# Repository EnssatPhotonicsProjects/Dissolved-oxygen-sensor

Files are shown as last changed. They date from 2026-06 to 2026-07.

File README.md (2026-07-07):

<p align="center">
  ENSSAT Logo
</p>

# Dissolved-oxygen-sensor

## Description

This project aims to develop a low-cost optode for measuring dissolved oxygen concentration in water, a key indicator of the health of marine environments. The project is conducted by students in photonics from Enssat in collaboration with the European Institute for Marine Studies (IUEM) and is part of an open-source initiative to facilitate easy and cost-effective replication of the device.

This GitHub repository contains all the necessary resources and instructions for understanding and making the device.

The document [Oximeter overview](Oximeter_overview.pdf) aims to provide an overview of the technical aspects of our sensor.

## Features

- Measures the percentage of dissolved oxygen within a range of 0 to 105 %.
- Low-cost (approximately ??), low-tech, and open-source design.
- Portable

## Principle of dissolved oxygen sensor

<p align="center">
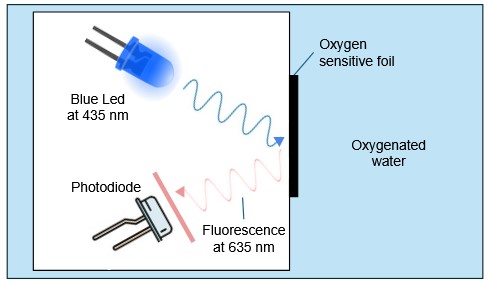
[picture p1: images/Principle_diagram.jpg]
Principle diagram
  
</p>
The measurement principle is based on the use of a luminophore. An emitting blue light is absorbed by a sensitive foil exposed to water. Then it returns red light through fluorescence. By measuring the phase shift between the blue and red signal, the concentration of dissolved oxygen can be determined.

## Functionality

<p align="center">
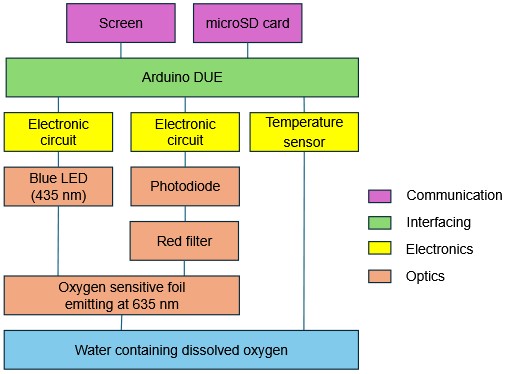
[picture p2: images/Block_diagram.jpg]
Block diagram
  
</p>

The Arduino DUE coordinates the entire system. To ensure speed and accuracy, the microcontroller uses synchronous detection. It drives a blue LED (435 nm) for excitation and detects the resulting fluorescence at 635 nm using a photodiode (isolated by a red filter). A temperature sensor is installed for measurements. Finally, the data is displayed on the OLED screen and saved to the MicroSD card.

## Components

The main components are:

| Component | Description |
|---|---|
| LED | Light Emitting Diode for blue excitation |
| Oxygen sensitive foil | Emits red fluorescence linked to the oxygen concentration |
| Photodiode | Detects red fluorescence |
| Arduino | Microcontroller for processing |
| Temperature Sensor | Measures the temperature |
| OLED Screen | Displays values |
| MicroSD Card Shield | Saves data to a MicroSD card |

For a detailed list of components with the references, please refer to the [Components List](hardware/components.md).

## Construction of the device : OXIMETER

### Prerequisites

- Arduino IDE
- Electronic components
- Soldering equipment
- 3D printer
- Laser cutter

### Installation Steps

1. **Clone the Repository:**

   ```bash
   git clone https://github.com/EnssatPhotonicsProjects/Dissolved-oxygen-sensor.git
   ```

### Assembling the dissolved oxygen sensor

Follow the steps of the [assembly guide](assembly_guide.md) to build the dissolved oxygen sensor.

## Avenues for Improvement

- ...

Contributions are welcomed to improve these points.

## To contribute

Contributions to this project are welcomed. To contribute, follow these steps:

1. **Fork the repository** and create your branch:

   ```bash
   git checkout -b my-new-feature
   ```

2. **Make your changes** and test them thoroughly.

3. **Document your changes** in the [EXTERNAL_CONTRIBUTIONS](EXTERNAL_CONTRIBUTIONS.md) file. Begin the file with your name, location and date.

4. **Submit a Pull Request** with a detailed description of your changes.

## Contributors

Team 2025-2026 :
- Arthur Allaeys (IntricationQuantique)
- Elisa Charron (Quazou54)
- Brice Chupin (bricechup)
- Léon Dolaine
- Constant Ekpo
- Ethan Geffroy
- Nathan Maës
- Alexandre Martin-Lefèvre
- Adam Monzon
- Lucile Pointud
- Sean Swidurski

## Acknowledgments

The authors warmly thank Laurent Bramerie, Thierry Chartier, Antoine Courtay supervisors of the project at Enssat, Philippe Laborie (Laboratoire de physique corpusculaire, Caen, France) and Etienne Poirier (IUEM, Plouzané, France), members of the steering committee, for their advice and support throughout the project. 

Special thanks to Etienne Poirier for giving the idea of the project, helping us, trusting us and welcome us at IUEM in the last days of the project.

Authors are also very grateful to Pierre Guilleme teacher at Enssat, and Jean-Philippe Lesault, technician at Enssat, for their advice and technical support. Specific thanks to Yvan Guilloit, in charge of the MakerSpace at IUT de Lannion, France, for his help in the integration of the device in the waterproof box.

The dissolved oxygen sensor project started in september 2025 with a first team of Enssat students.

## License

This project is licensed under [CC BY-SA 4.0]. Please see the [LICENSE](LICENSE.md) file for more details.

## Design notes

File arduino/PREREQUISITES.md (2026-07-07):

# Prerequisites & code configuration

This document outlines the arduino dependencies and code architecture required to compile and run the open-source dissolved oxygen sensor (Oximeter) firmware.

> **WARNING :** This firmware is designed strictly for the Arduino Due (3.3V ARM Cortex-M3 SAM3X8E architecture). It relies on low-level hardware registers (Hardware Timers `TC0`, analog-to-digital conversion `ADC` and digital-to-analog conversion `DAC`).

## Arduino dependencies

Before compiling in the Arduino IDE, ensure the following external libraries are installed via the Library Manager : <br>
(`Sketch` > `Include Library` > `Manage Libraries...`)

### External libraries to install:
* **`U8g2`** : Monochrome display library for the OLED display.
* **`OneWire`** : Digital communication protocol for the OneWire temperature probe.
* **`DallasTemperature`** : Data extraction for the OneWire temperature probe.

### Native libraries (Included with Arduino SAM Boards package):
* **`SPI`** : High-speed communication for the MicroSD card shield.
* **`SD`** : FAT16/FAT32 file system management for data logging.
* **`Wire`** : I2C communication for the OLED display (utilizing the Due's secondary I2C port `Wire1`).

## Code architecture

The firmware follows the single responsibility principle, dividing the system into isolated modules. All of these modules must be placed in a folder named [Oximeter](arduino/Oximeter/):

```text
Oximeter/
├── Oximeter.ino              # System orchestrator (main loop and measurement cycle sequencing)
├── synchronous_detection.*   # Low-level lock-in amplifier (Timer ISRs, DAC sine modulation, ADC reads)
├── tools.*                   # Mathematical models (F0 noise subtraction, Stern-Volmer, polynomial fit)
├── complex.*                 # Custom operator for complex number arithmetic (+, -, *, /)
├── temperature.*             # Temperature reads with safe interrupt management (Non-blocking)
├── display.*                 # OLED visual interfaces (boot status, live results, progress bar)
└── microSD_card.*            # Data logging (automatic session file creation and TSV data writing)

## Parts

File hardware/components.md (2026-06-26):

# List of components

## Optical components

| Component | Manufacturer - Ref | Seller - Ref | Quantity | Price per unit |
|---|---|---|---|---|
|Oxygen sensitive spot|Presens - PSt3-SA series|[Presens - PSt3-SA23-D5-YOP-US](https://www.presens.de/oemcustom/detail/self-adhesive-oxygen-sensor-spot-sp-pst3-sa)|1|33.75 €|
|LED|Thorlabs - LED430L|[Thorlabs - LED430L](https://www.thorlabs.com/item/LED430L)|1|13.29 €|
|Photodiode|Thorlabs - FDS100|[Thorlabs - FDS100](https://www.thorlabs.com/item/FDS100)|1|15.95 €|
|Red filter|Lee Filters - 182 Light Red|[Lee Filters - 182 Light Red](https://www.la-bs.com/ArticleDetails.aspx?Code=FL182)|1|12.16 €|

## Electronic components

| Component | Manufacturer - Ref | Seller - Ref | Quantity | Price per unit |
|---|---|---|---|---|
|Carte Arduino DUE|Arduino - A000062|[RS - 769-7412](https://fr.rs-online.com/web/p/arduino/7697412)|1|53.35 €|
|OLED Screen 128x64|Midas - MDOB128064V2V-YI|[RS - 225-6203](https://fr.rs-online.com/web/p/afficheurs-oled/2256203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)|1|14.98 €|
|MicroSD Card Shield|Whadda - WPI304N|[GO TRONIC - 38094](https://www.gotronic.fr/art-modules-pour-microsd-wpi304n-36272.htm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)|1|9.90 €|
|Temperature sensor|TRU COMPONENTS TC-9445340|[Conrad - 2361335-62](https://www.conrad.fr/fr/p/tru-components-tc-9445340-capteur-de-temperature-1-pc-s-convient-pour-kits-de-developpement-arduino-2361335.html)|1|6.99 €|
|Powerbank|Output 5 V - 2.4 A, dim. 100x50x25 mm max|[VRURC 2000mAh mini power bank](https://www.amazon.fr/gp/product/B099F29H7Y?smid=A2BNE5LRDUXQ6R&th=1)|1|30 €|
|Voltage converter|Analog Devices - MAX660CPA+|[Mouser - 700-MAX660CPA](https://www.mouser.fr/ProductDetail/700-MAX660CPA)|1|9.37 €|
|Transistor|Micro Commercial Components - PN2222A-AP|[Mouser - 833-PN2222A-AP](https://www.mouser.fr/ProductDetail/Micro-Commercial-Components-MCC/PN2222A-AP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)|1|< 1 €|
|Operational amplifier|Texas Instruments - TL081CP|[Mouser - 595-TL081CP](https://www.mouser.fr/ProductDetail/595-TL081CP)|2|0.60 €|
|Resistor 50 Ω|||1|< 1 €|
|Resistor 66 Ω|||1|< 1 €|
|Resistor 1,2 kΩ|||2|< 1 €|
|Resistor 4,6 kΩ|||2|< 1 €|
|Resistor 10 kΩ|||1|< 1 €|
|Resistor 912 kΩ|||1|< 1 €|
|Capacitor 1 nF|||1|< 1 €|
|Capacitor 47 nF|||1|< 1 €|
|Capacitor 150 µF|||2|< 1 €|

## Case and support components

| Component | Reference | Quantity | Price per unit |
|---|---|---|---|
| Filament PLA black | | | |
| PVC sleeve | 100 mm diameter | 1 | 1.50 € |
| PVC plug | 100 mm diameter | 2 | 3.70 € |
| PMMA thickness 2 mm | | | € |
| PMMA thickness 3 mm | | | € |
| Screws, nuts, washers, spacers | - | | € |

## Final price

The price is estimated in **June 2026** at ** without delivery**.

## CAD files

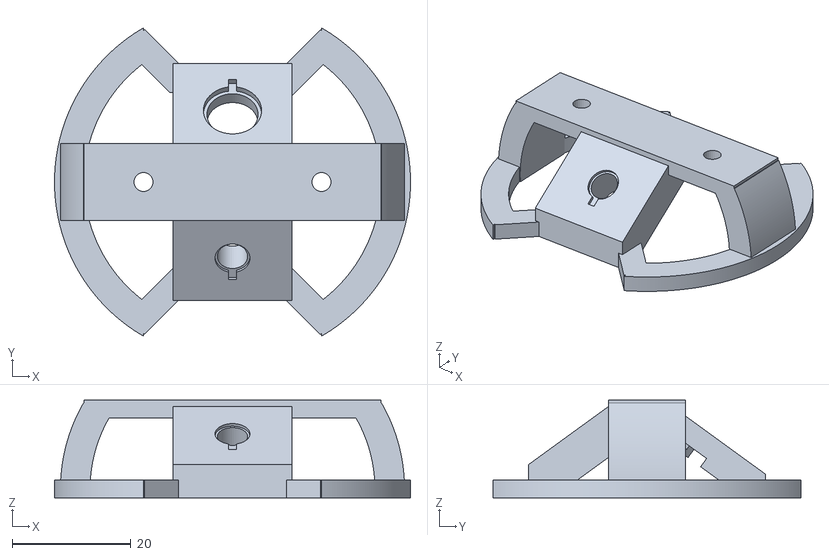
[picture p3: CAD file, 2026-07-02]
hardware/Ready_to_print_LED-photodiode-support.stl
60.0 x 52.0 x 16.5

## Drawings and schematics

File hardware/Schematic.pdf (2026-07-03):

## 3 JP1

## 6 BT

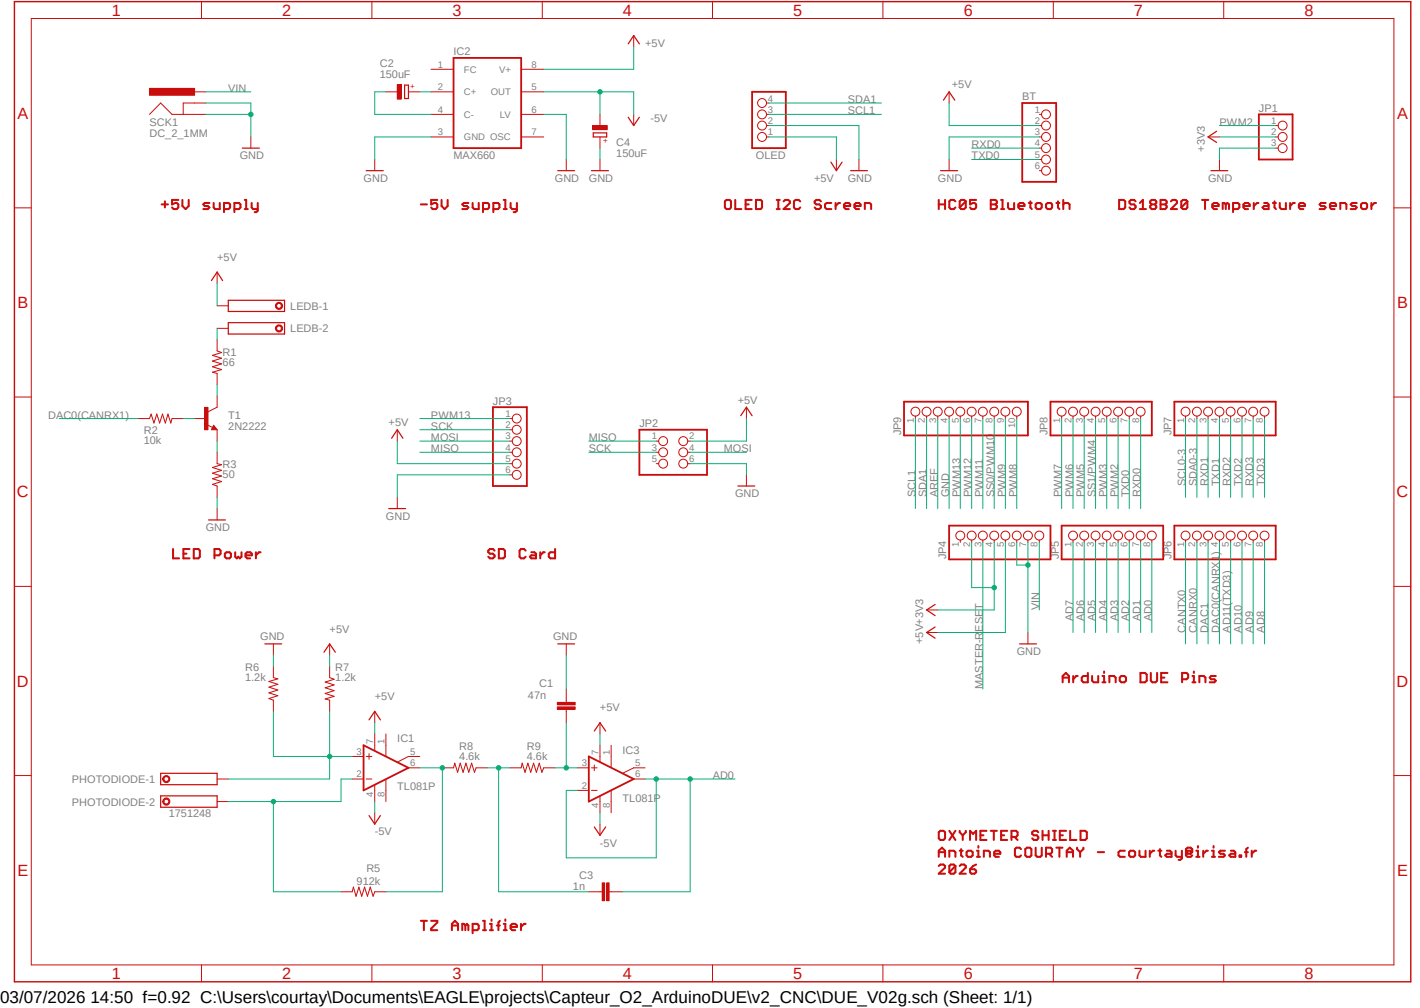
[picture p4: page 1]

03/07/2026 14:50 f=0.92 C:\Users\courtay\Documents\EAGLE\projects\Capteur_O2_ArduinoDUE\v2_CNC\DUE_V02g.sch (Sheet: 1/1)

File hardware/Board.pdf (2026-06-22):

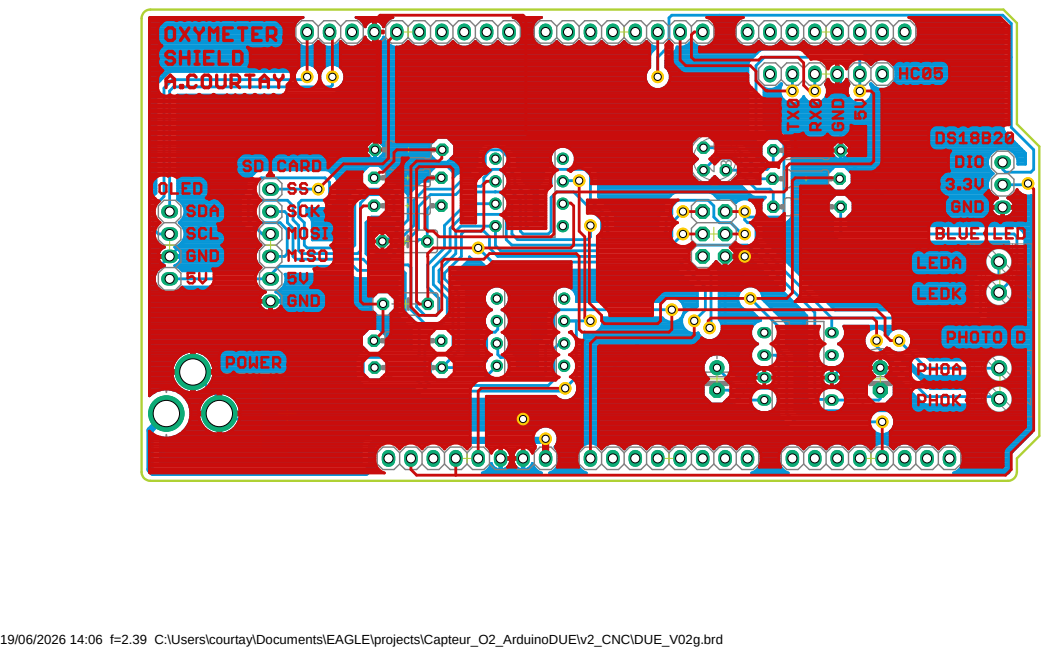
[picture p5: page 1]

19/06/2026 14:06 f=2.39 C:\Users\courtay\Documents\EAGLE\projects\Capteur_O2_ArduinoDUE\v2_CNC\DUE_V02g.brd

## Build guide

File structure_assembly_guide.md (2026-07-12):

# Assembly Guide for Support Structures

This guide provides detailed instructions on how to assemble the Dissolved-oxygen-sensor structures.

## Prerequisites

Before starting the assembly process, ensure you have the following tools and components ready:

- Components from the [Components List](hardware/components.md)
- PVC glue
- Sandpaper
- PVC stripper
- Laser cutter
- Screws, nuts, washers, spacers
- Paper towel or rag
- Wires (red and black)
- Soldering station

## Step 1 : Assemble the LEDs and photodiode support

Start by soldering wires to the LEDs and photodiode terminal. Pay attention to the polarity of the terminals : you can solder a red wire on the + terminals of the LED and the cathode terminal of the photodiode. A black wire can be soldered on the - terminals of the LEDs and on the anode of the photodiode.

When this is done, you can assemble following components :
- Blue LED
- Photodiode
- (Red filter : 19 x 18 mm) X2
- [3D printed support](Ready_to_laser_cut_LED-photodiode-support.stl)

<p align="center">
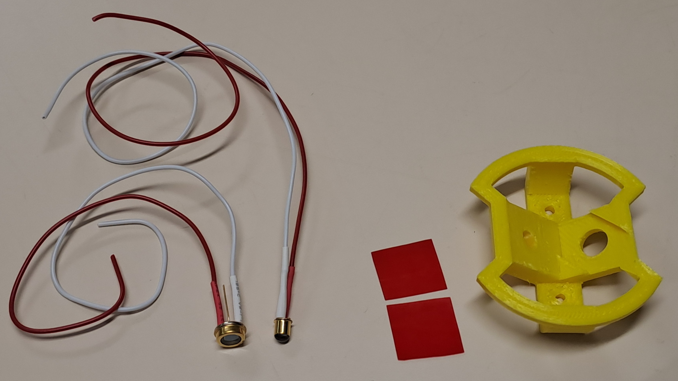
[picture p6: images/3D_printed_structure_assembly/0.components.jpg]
0.components
  
</p>

1. Position the LED and the photodiode in their location. If they do not fit, you can lightly file the inside of the holes. The components must be perfectly held by the support and must not move. The wires must come out of the back of the bracket. You can add small pieces of adhesive tape to the edges of the LED and the photodiode to ensure they do not slip out of the holders.

<p align="center">
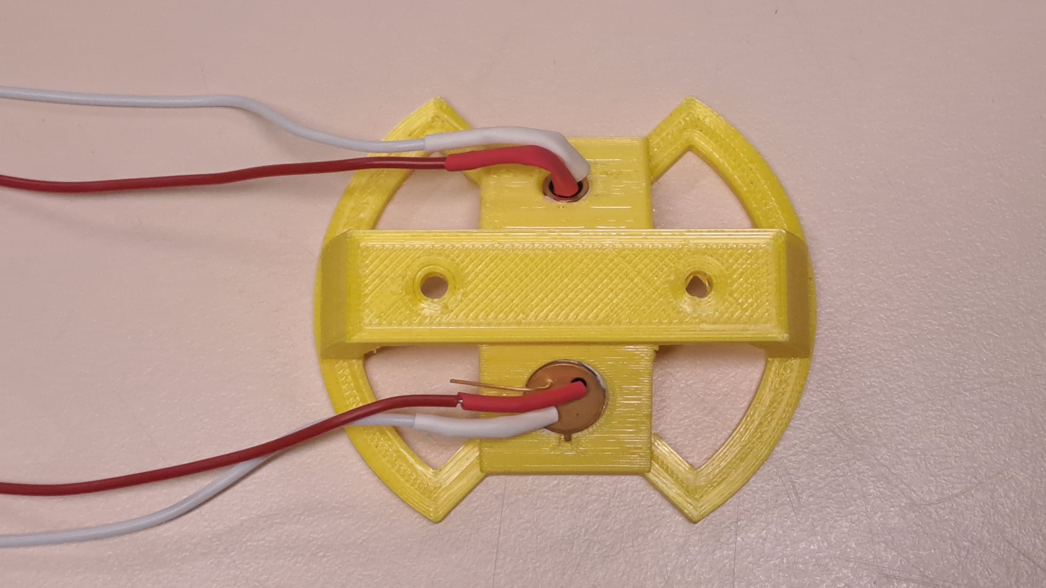
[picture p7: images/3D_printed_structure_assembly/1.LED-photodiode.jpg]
1.LED-photodiode
  
</p>

2. Add the two pieces of red filter. You can slide them in front of the photodiode location.

<p align="center">
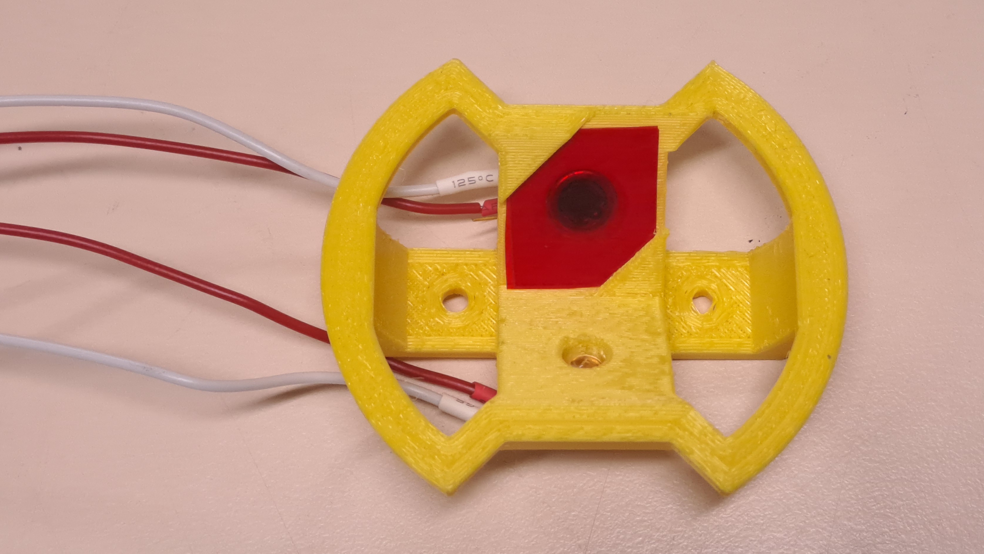
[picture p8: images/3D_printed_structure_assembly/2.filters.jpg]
2.filters
  
</p>

## Step 2 : Assemble the internal structure

The materials required for this step are :
- The Arduino DUE board
- The PCB board with all the electronic components (Screen, SD Card shield, temperature sensor)
- 3 screws, diameter 3 mm, length 5?? mm + 6 nuts
- 16 spacers of 30 mm
- 4 countersunk screw, diameter 3 mm, length 8?? mm + nuts + washers
- 2 screws, diameter 3 mm, length 10?? mm + nuts 
- 4 screws, diameter 2 mm, length ?? mm + 8 nuts + washers
- A powerbank (100 x 50 x 2.5) mm max
- A output power supply and angled USB output cable
- The LED and photodiode AD support made in the previous step
- PMMA sheet or wood, thickness 3 mm
- PMMA sheet, thickness 1.5 mm
- Screwdrivers
- Laser cutter

<p align="center">
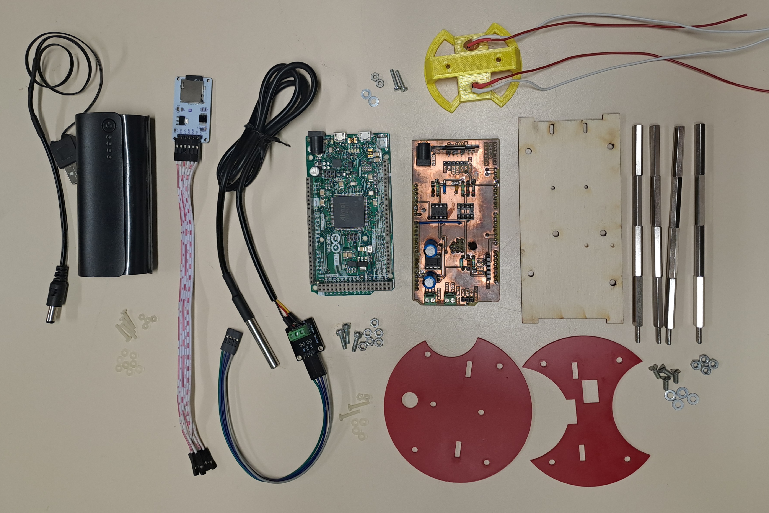
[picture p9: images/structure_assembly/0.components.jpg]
0.components
  
</p>

1. Cut the structure in the PMMA sheets with the laser cutter. In 1.5 mm PMMA, cut the [plates](hardware/Ready_to_laser_cut_plates.svg). In 3 mm PMMA, cut the [mount](hardware/Ready_to_laser_cut_mount.svg).

<p align="center">
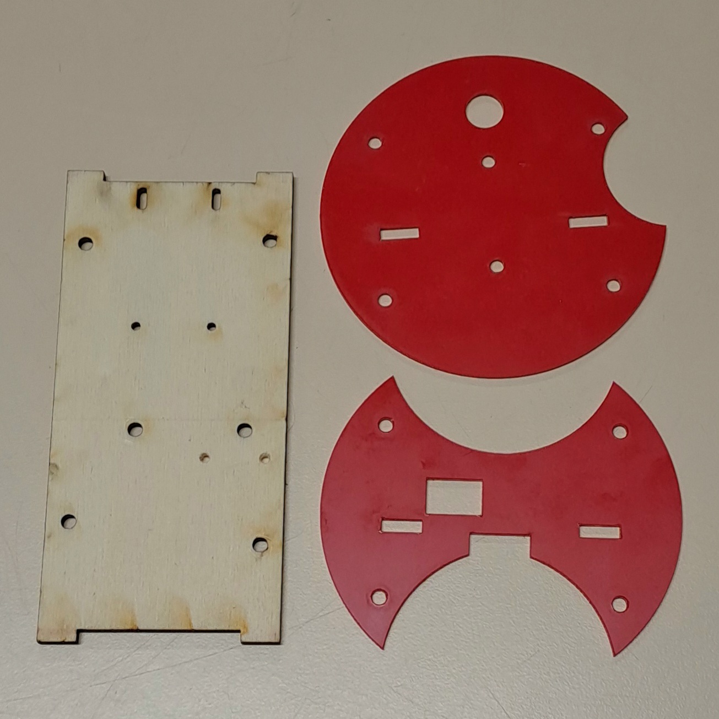
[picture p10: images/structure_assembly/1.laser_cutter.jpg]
1.laser_cutter
  
</p>

2. Screw 3 screws and nuts to the Arduino board, as shown in the photo below. Connect the PCB to the Arduino board.

<p align="center">
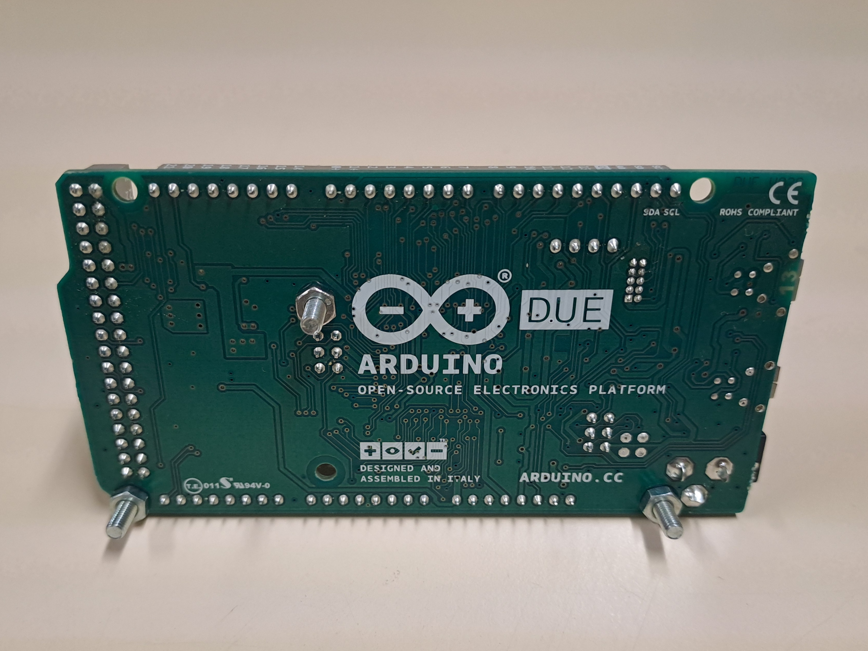
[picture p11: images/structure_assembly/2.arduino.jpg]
2.arduino
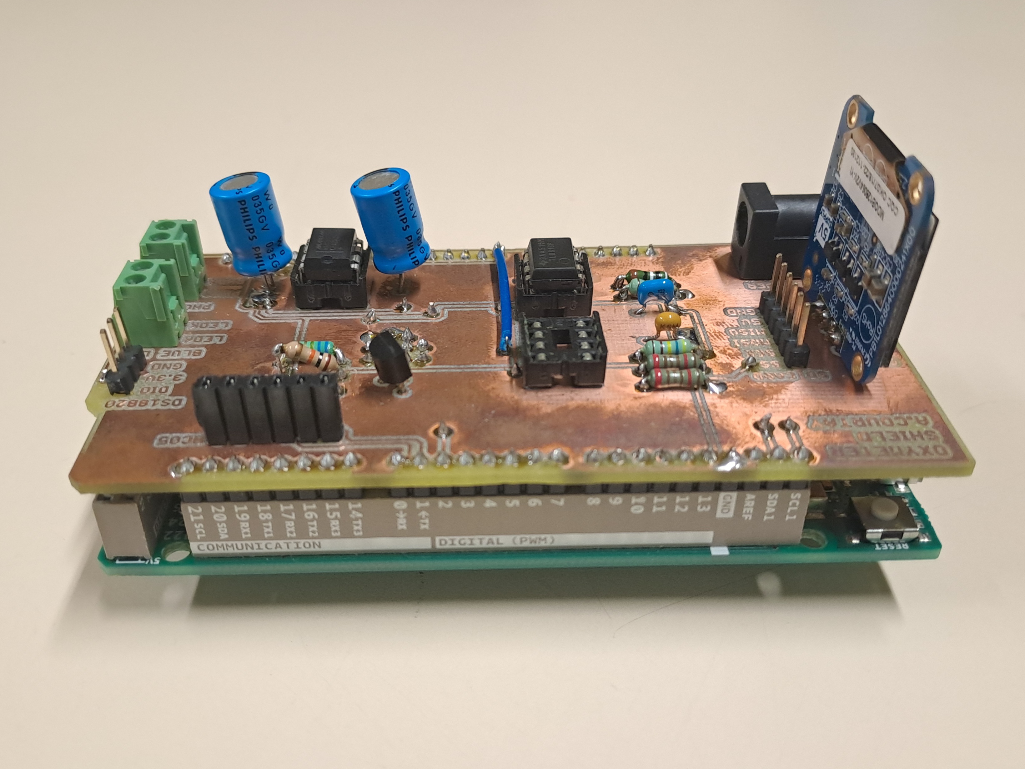
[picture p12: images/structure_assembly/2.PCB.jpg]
2.PCB
   
</p>

3. Take the face plate. Locate the side where the Arduino board goes. On the opposite side, screw the SD Card shield. Put a nuts between the shield and the plate.

<p align="center">
  3.modules
</p>

4. Screw the Arduino board on the opposite face of the plate.

<p align="center">
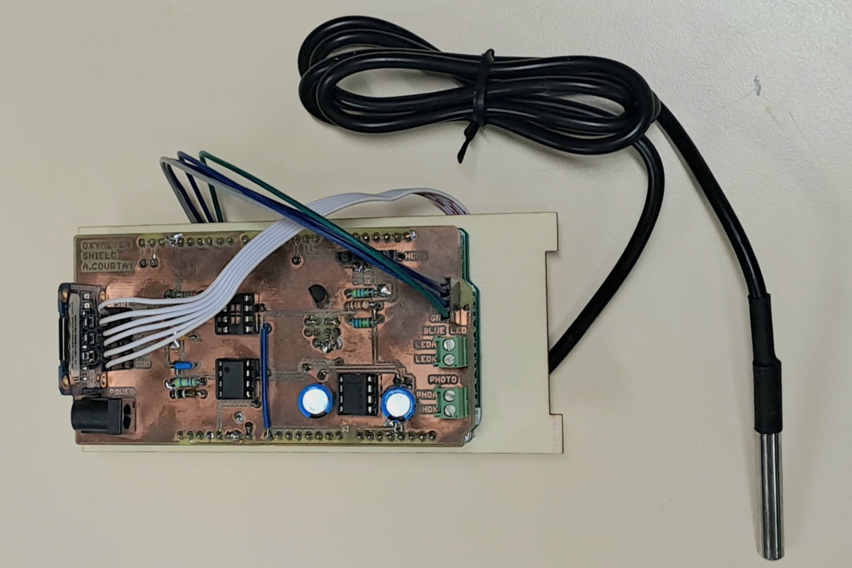
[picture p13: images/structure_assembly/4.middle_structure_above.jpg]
4.middle_structure_above
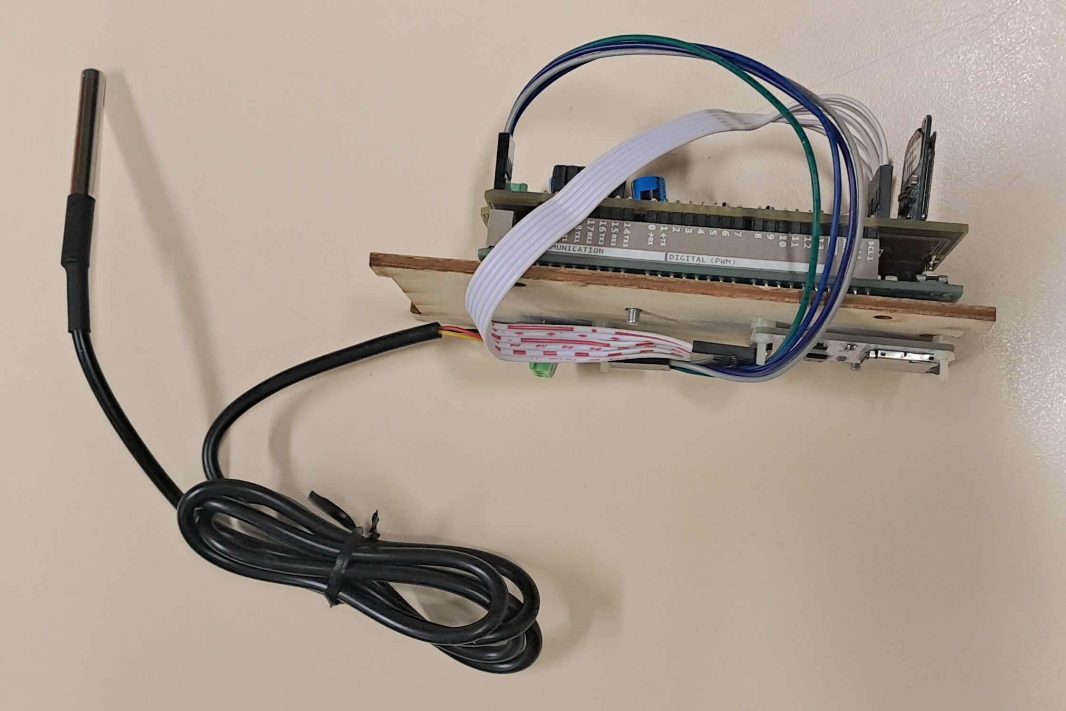
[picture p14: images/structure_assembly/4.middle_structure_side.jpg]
4.middle_structure_side
   
</p>

5. Take the bottom plate and the LED and photodiode support. Screw this support under the bottom plate. Make sure that the large hole in the plate is on the same side as the wires. Pass the wires through the hole.

<p align="center">
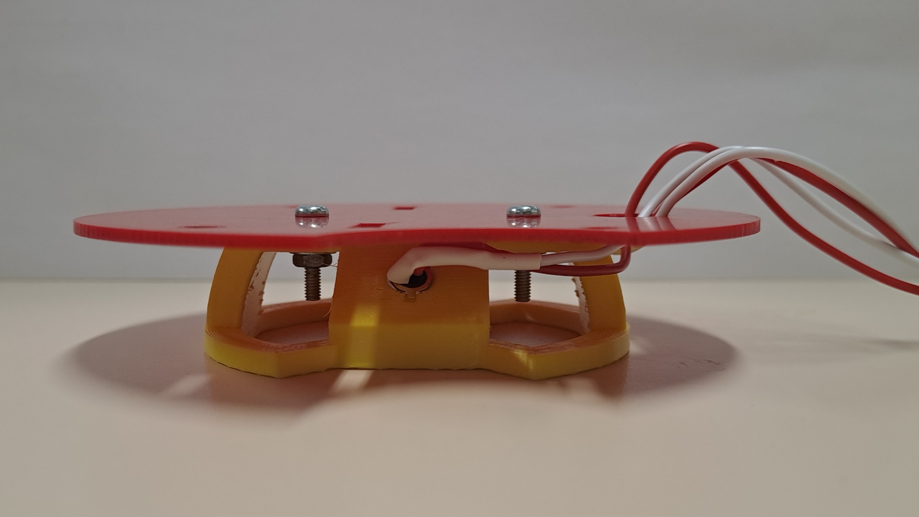
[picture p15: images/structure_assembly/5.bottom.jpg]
5.bottom
  
</p>

6. Screw the LED and photodiode wires into terminal strips of the PCB. Make sure to connect the cathode and anode to the correct terminals.

<p align="center">
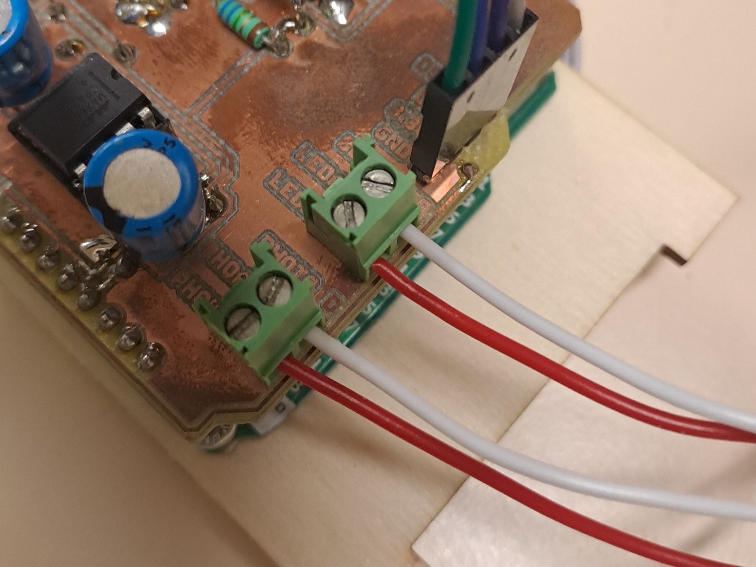
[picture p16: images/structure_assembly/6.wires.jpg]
6.wires
  
</p>

7. Screw the 30 mm spacers into the four corners of the middle plate and put the middle structure, bend the wires of the LED and photodiode, without moving LED and photodiode.

<p align="center">
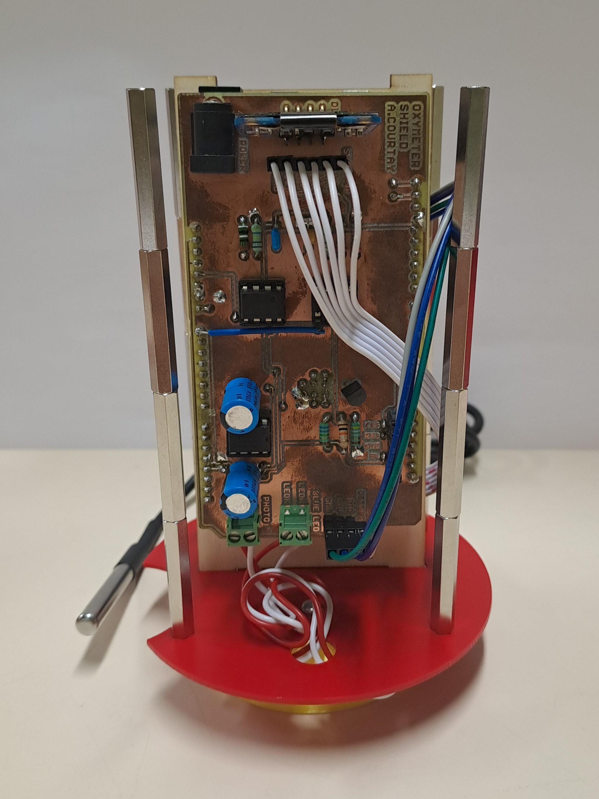
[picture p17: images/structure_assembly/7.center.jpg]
7.center
  
</p>

8. Screw the top plate.

<p align="center">
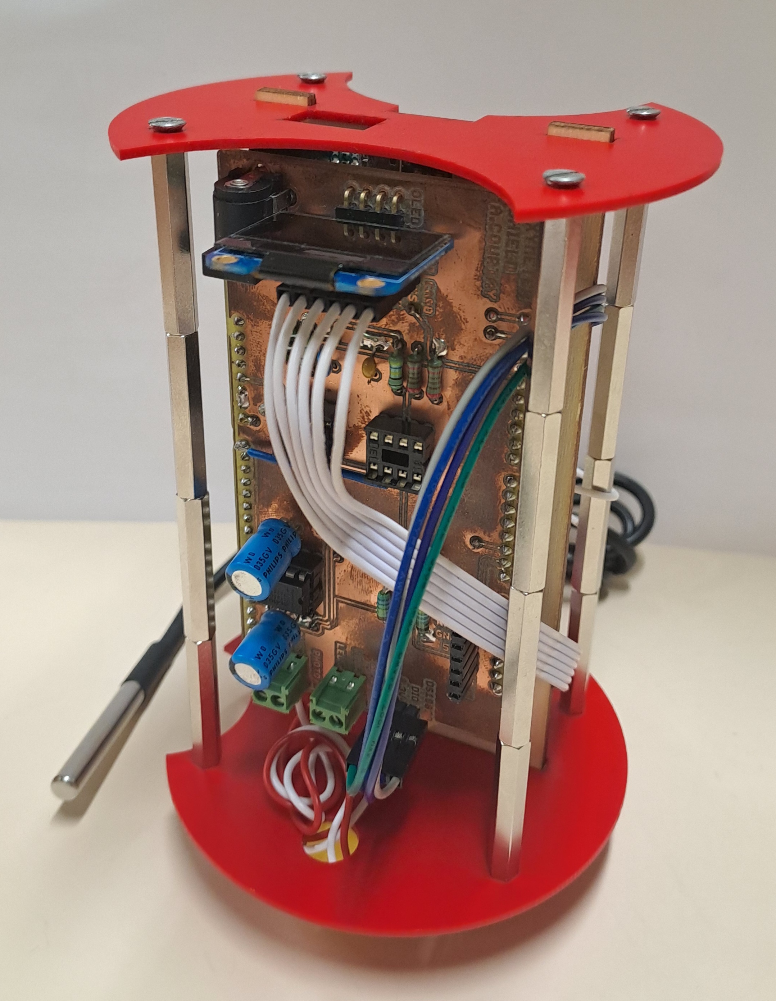
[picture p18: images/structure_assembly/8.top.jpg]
8.top
  
</p>

9. Put the powerbank and the alimentation cable. Fasten it to the spacers with a cable tie.

<p align="center">
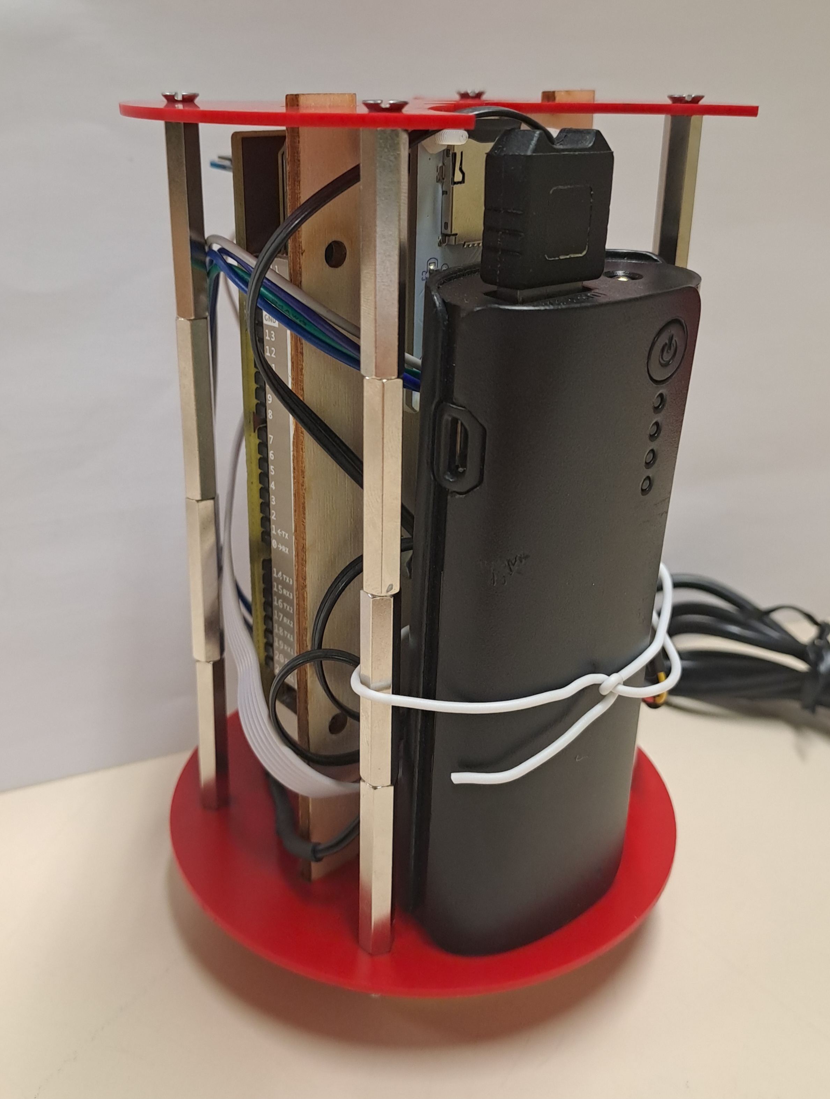
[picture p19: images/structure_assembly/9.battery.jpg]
9.battery
  
</p>

10. Attach the temperature sensor cable to the spacers located between the battery and the opening in the plate. The cable should extend upwards, with a disponible length of approximately 40 cm, to facilitate positioning within the housing.

<p align="center">
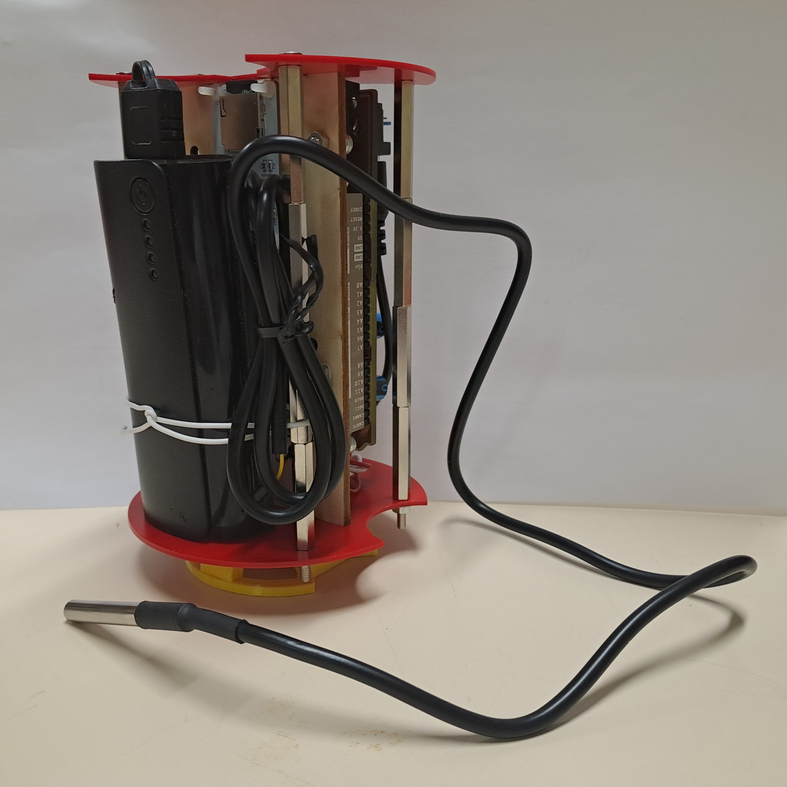
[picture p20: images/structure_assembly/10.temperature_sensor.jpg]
10.temperature_sensor
  
</p>

## Step 3 : Assemble the waterproof box

In this step, you will need :
- PVC sleeve
- Two PVC inspection plugs
- transparent PMMA plate
- cable gland (taille ??)
- PVC glue
- Sandpaper
- PVC stripper
- Laser cutter
- Paper towel or rag

## Step 4 : Assemble the fluorometer

Slide the internal structure into the box. It must be at the bottom and must not move. Switch on the battery, and close the box.

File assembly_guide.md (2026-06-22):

# Assembly Guide for oxymeter

This guide provides detailed instructions on how to assemble the oxymeter device.

## Prerequisites

Before starting the assembly process, ensure you have the following tools and components ready:

- Arduino IDE installed on your computer
- All electronic components listed in the [Components List](hardware/components.md)
- 3D printer for printing support structures
- Laser cutting for support structures
- Soldering equipment for assembling electronic circuits
- Basic hand tools (screwdrivers, pliers, etc.)

## Step 1: Clone the Repository

To get started, clone the project repository to your local machine:

```bash
git clone https://github.com/EnssatPhotonicsProjects/Dissolved-oxygen-sensor.git
```
## Step 2: Assemble the Electronic Components

### Using a Breadboard

If you are prototyping or prefer not to use a PCB, you can assemble the circuit on a breadboard. Refer to the [Schematic.pdf](hardware/Schematic.pdf) for detailed connections.

### Using a PCB

1. Download the PCB design file from the repository:
2. Order the PCB from a manufacturer or print it if you have the necessary equipment.
3. Solder the components onto the PCB following the schematic diagram.

## Step 3: Assemble the Support Structures

Use the provided STL file to 3D print the necessary support structures with PLA filament, and a filling density of ??%. Printing takes about ?? hours : 

- [LED and Photodiode Support](hardware/3D_ready_to_print_LED-Photodiode-Support.stl)

Assemble the parts according to the instructions provided in the [Assembly Manual](structure_assembly_guide.md).

## Step 4: Upload the Arduino Code

1. Open the `.ino` file in the Arduino IDE.
2. Connect your Arduino board to the computer.
3. Select the correct board and port in the Arduino IDE.
4. Upload the code to the Arduino board.

## Step 5: Calibration

## Troubleshooting

If you encounter any issues during the assembly or operation of the device, open an issue in the repository.

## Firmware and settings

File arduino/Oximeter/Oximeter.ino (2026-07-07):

/**
 * @file Oximeter.ino
 * @brief Main execution routine for the open-source dissolved oxygen sensor.
 * ----------------------------------------------------------------------------
 * * This file acts as the system orchestrator. It initializes all hardware 
 * modules (OLED, MicroSD, Temperature, and Synchronous Detection). In the 
 * main loop, it handles:
 * [1] Acquisition: Triggers the measurement cycle and reads sensors.
 * [2] Math translation: Delegates the calculation of phase shift (theta) 
 * and O2 concentrations to the external mathematical module tools.cpp
 * [3] Output: Displays and logs the processed data in real-time.
 * ----------------------------------------------------------------------------
 * @attention To calibrate the OXIMETER (background noise F0, phase offset 
 * or Stern-Volmer constants), edit the variables inside tools.cpp!
 */

#include "tools.h"
#include "complex.h"
#include "display.h"
#include "temperature.h"
#include "microSD_card.h"
#include "synchronous_detection.h"


// In order to test and prepare the system
void setup() {
  SerialUSB.begin(115200);
  delay(3000);

  SerialUSB.println("-------- CONNEXION OXIMETER --------");
  delay(100);

  init_display();
  delay(100);
  
  init_temperature();
  delay(100);

  init_sd_card();
  delay(100);

  init_synchronous_detection();
  delay(3000); // To have time to read inits
}

// In order to measure, calculate, display results and log results
void loop() {
  // Waiting screen for measuring
  SerialUSB.println("-------------- Mesure --------------");
  show_measuring(0);

  // [1] Acquisition -> synchonous detection.cpp + temperature.cpp
  Complex fourier = synchronous_detection(5.0);
  float temperature = read_temperature_retry(3);

  // [2] Mathematical translations -> tools.cpp
  float theta = calculate_theta(fourier);
  float o2_estimated_percent = calculate_o2_polynomial(theta, temperature);
  float o2_sv_percent = calculate_o2_stern_volmer(theta);

  // [3] Display and logging data -> display.cpp + microSD_card.cpp
  update_display(temperature, o2_estimated_percent, o2_sv_percent);
  log_data(temperature, theta, o2_estimated_percent, o2_sv_percent);

  delay(3000); // To have time to read results
}

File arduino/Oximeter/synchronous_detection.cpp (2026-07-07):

#include "synchronous_detection.h"
#define DAC_RESOLUTION 12

// Parameters for emitting signal
const float FREQUENCY = 5000.0;
const int POINTS_PER_PERIOD = 16;
const float SAMPLE_RATE = FREQUENCY * POINTS_PER_PERIOD;
const float Vmin = 0.9;
const float Vmax = 1.5;
const float Vref_min = 0.55; // 3.3*(1/6) = 0.55 V, limitation between 0 and 3.3V
const float Vref_max = 2.75; // 3.3*(5/6) = 2.75 V
const int MAX_DAC = (1 << DAC_RESOLUTION) - 1;
const int TRIG_SCALE = 2000;

// Global variables
volatile uint16_t outTable[POINTS_PER_PERIOD];
volatile int32_t sinTable_Int[POINTS_PER_PERIOD];
volatile int32_t cosTable_Int[POINTS_PER_PERIOD];
volatile uint8_t tableIndex = 0;

volatile int64_t avrg_r_accum = 0;
volatile int64_t avrg_i_accum = 0;
volatile uint32_t target_points = 0;
volatile uint32_t current_points = 0;
volatile bool collection_active = false;
volatile bool collection_done = false;

uint16_t inputSample_Sonde = 0;

// In order to start synchronous detection
void start_synchronous_detection() {
    dacc_enable_channel(DACC, 0); // DAC on 

    volatile uint32_t dummy = TC0->TC_CHANNEL[0].TC_SR;
    (void)dummy;
    NVIC_ClearPendingIRQ(TC0_IRQn);
    NVIC_EnableIRQ(TC0_IRQn);

    TC_Start(TC0, 0); // Launch Timer -> LED on
}

// In order to stop synchronous detection
void stop_synchronous_detection() {
    TC_Stop(TC0, 0); // Break Timer

    NVIC_DisableIRQ(TC0_IRQn);
    volatile uint32_t dummy = TC0->TC_CHANNEL[0].TC_SR;
    (void)dummy;
    NVIC_ClearPendingIRQ(TC0_IRQn);

    dacc_write_conversion_data(DACC, 0); // LED off
    dacc_disable_channel(DACC, 0); // DAC off
}

// In order to init synchronous detection
bool init_synchronous_detection() {
    if (DACC == NULL || ADC == NULL || TC0 == NULL) {
        u8g2.drawStr(0, 58, "Synchro Detec : X");
        u8g2.sendBuffer();

        SerialUSB.println("Error : Failed to init sync detec.");
        return false;
    }

    // Creation of signal tables
    for (int i = 0; i < POINTS_PER_PERIOD; i++) {
        float theta = 2.0 * PI * i / POINTS_PER_PERIOD;
        float s = sin(theta);
        float c = cos(theta);

        float V = Vmin + (Vmax-Vmin) * (0.5*s+0.5);
        outTable[i] = (uint16_t)(MAX_DAC*(V-Vref_min) / (Vref_max-Vref_min));

        sinTable_Int[i] = (int32_t)(s*TRIG_SCALE);
        cosTable_Int[i] = (int32_t)(c*TRIG_SCALE);
    }

    // Material configuration -> DAC, ADC, Timer
    pmc_enable_periph_clk(ID_DACC);
    dacc_reset(DACC);
    dacc_set_transfer_mode(DACC, 0);
    dacc_set_channel_selection(DACC, 0);
    dacc_enable_channel(DACC, 0);

    pmc_enable_periph_clk(ID_ADC);
    adc_init(ADC, SystemCoreClock, ADC_FREQ_MAX, ADC_STARTUP_FAST);
    adc_configure_timing(ADC, 0, ADC_SETTLING_TIME_3, 1);
    adc_enable_channel(ADC, ADC_CHANNEL_7);
    adc_disable_interrupt(ADC, 0xFFFFFFFF);
    adc_start(ADC);

    pmc_enable_periph_clk(ID_TC0);
    uint32_t rc = 42000000/SAMPLE_RATE;
    TC_Configure(TC0, 0, TC_CMR_WAVE | TC_CMR_WAVSEL_UP_RC | TC_CMR_TCCLKS_TIMER_CLOCK1);
    TC_SetRC(TC0, 0, rc);
    TC0->TC_CHANNEL[0].TC_IER = TC_IER_CPCS;
    TC0->TC_CHANNEL[0].TC_IDR = ~TC_IER_CPCS;
    
    NVIC_SetPriority(TC0_IRQn, 8);
    
    // End of init
    //stop_synchronous_detection();

    u8g2.drawStr(0, 58, "Synchro Detec : OK");
    u8g2.sendBuffer();

    SerialUSB.println("4. init_sync_detec OK");
    return true;
}

// In order to measure in loop
Complex synchronous_detection(float average_duration) { 
    // Number of measurement points with the given delta t and signal parameters 
    target_points = (uint32_t)ceil(average_duration*FREQUENCY)*POINTS_PER_PERIOD;
    SerialUSB.print("target_points = "); SerialUSB.print(target_points); 
    SerialUSB.print(" in "); SerialUSB.print(average_duration, 1); SerialUSB.println(" s");
    if (target_points == 0) return {0.0, 0.0};

    // Useful variables
    avrg_r_accum = 0;
    avrg_i_accum = 0;
    current_points = 0;
    collection_done = false;

    // LED on and Timer on -> beginning of collection
    start_synchronous_detection();
    collection_active = true;
    SerialUSB.print("Measuring : ");
    
    // Waiting for the collection to finish via the ISR interrupt
    uint32_t last_display_update = millis();
    while (!collection_done) {
        uint32_t now = millis();
        // Progress bar refreshed every 500 ms
        if (now - last_display_update > 500) {
            float ratio = (float)current_points/(float)target_points;
            int percent = (int)(ratio*100.0);
            
            SerialUSB.print(percent); SerialUSB.print(" % ");

            show_measuring(percent);
            last_display_update = now;
        }
    }

    // LED off and Timer off -> end of collection
    stop_synchronous_detection();
    SerialUSB.println("-> Done");

    // Results
    // Conversion to true voltage (*3.3/4095), averaging (*target_points), s/c scale cancellation (*TRIG_SCALE), synch demodulation (*2.0)
    float conversion_factor = (2.0*3.3) / ((float)target_points*TRIG_SCALE*4095.0);
    Complex result;
        result.real = avrg_r_accum * conversion_factor;
        result.imag = avrg_i_accum * conversion_factor;

    SerialUSB.print("ADC read = "); SerialUSB.println(inputSample_Sonde); // Debug ADC read
    SerialUSB.print("fourier = "); print_complex(result); SerialUSB.println(" V");

    return result;
}


// In order to interrupt (ISR)
void TC0_Handler() {
    volatile uint32_t status = TC0->TC_CHANNEL[0].TC_SR;
    (void)status;

    // DAC on -> signal modulation
    DACC->DACC_CDR = outTable[tableIndex];

    // ADC read
    uint16_t inputSample = ADC->ADC_CDR[7];
    ADC->ADC_CR = ADC_CR_START;
    inputSample_Sonde = inputSample; // Debug ADC read

    // Accumulate data, real and imag
    if (collection_active) {
        avrg_r_accum += (int64_t)inputSample * cosTable_Int[tableIndex];
        avrg_i_accum += (int64_t)inputSample * sinTable_Int[tableIndex];
        
        current_points++;
        if (current_points >= target_points) {
            collection_active = false;
            collection_done = true; // End for the while loop
        }
    }

    // Managing signal Index
    tableIndex++;
    if (tableIndex >= POINTS_PER_PERIOD) {
        tableIndex = 0;
    }
}

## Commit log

2026-05-13 Revise assembly section for dissolved oxygen sensor
    Updated section title and description for clarity.
2026-05-19 Update README to reflect sensor terminology
2026-06-22 Update optical component reference for oxygen sensor
2026-06-22 Update voltage converter entry in components list
2026-06-23 Clarify instructions for understanding the device
2026-06-24 Created CITATION for dissolved oxygen sensor project
2026-07-03 Update schematic
2026-07-03 Rename images/1.laser_cutter.jpg to images/ structure_assembly/1.laser_cutter.jpg
2026-07-06 Change image paths in assembly guide
    Updated image paths to reflect new directory structure for 3D printed assembly images.
2026-07-06 Fix image filenames in structure assembly guide
    Updated image references in the assembly guide to use the correct filenames.
2026-07-06 Fix typo in assembly guide regarding PMMA cuts
2026-07-06 Fix grammar in Step 1 of assembly guide
    Corrected grammatical errors in assembly instructions.
2026-07-06 Fix image references in structure assembly guide
    Updated image references in the assembly guide to correct filenames and improve clarity.
2026-07-06 Add prerequisites documentation for arduino setup
    This document outlines the prerequisites for the open-source dissolved oxygen sensor firmware, including hardware requirements, software dependencies, and firmware architecture.
2026-07-06 Revise prerequisites and dependencies in documentation
    Updated prerequisites documentation for Arduino project, including hardware and software dependencies.
2026-07-06 Refine prerequisites documentation for Arduino Due
    Updated formatting and wording for clarity in prerequisites documentation.
2026-07-06 Update prerequisites for Arduino dependencies
    Added instructions for installing the U8g2 library for OLED display support.
2026-07-07 Revise prerequisites documentation for clarity
    Updated terminology from 'software dependencies' to 'arduino dependencies' and changed section title from 'Modular architecture' to 'Code architecture'.
2026-07-07 Fix typo in device name from OXYMETER to OXIMETER
2026-07-07 Update README with sensor features
    Added features section to README with sensor capabilities.
